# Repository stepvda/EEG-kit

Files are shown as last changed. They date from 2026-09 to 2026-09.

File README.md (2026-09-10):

# EEG Field Kit — Design & Production Package v2.4

**TI One Voice research programme** — [one.witysk.org](https://one.witysk.org), Brussels, Belgium
Board revision B · 2 September 2026

The complete manufacturing package for **EEG-CAR-01 Rev B**: a battery-powered, 16-channel EEG headset
built around an ESP32-S3 carrier board, together with the helmet and enclosure, the electrode harness,
the firmware, the production test programme and fixtures, and all the packing, quality and regulatory
documentation needed to produce the finished kit — flight case included.

The package is designed so that a manufacturer can quote, review and build from it directly: the
Gerbers, drill files, netlist, BOM and CPL files are included, along with every printed part, the
assembly work instructions and an end-to-end test programme that runs from Chrome over USB. For the
study itself — participants, collaborators, grant bodies and funders — see
[one.witysk.org/studies](https://one.witysk.org/studies).

---

## Status at a glance

**Nothing in this package has been manufactured or measured.** No board has been fabricated, no part
has been printed, no firmware has been flashed to silicon, and no electrode has touched a person.
Every performance figure is calculated, and each is labelled as calculated where it appears.

| Area | State |
|---|---|
| Carrier board routing | **Complete.** 145 of 145 nets connected, 0 DRC violations. **Released for review under RFQ-EEG-002A — not yet released for fabrication:** no human layout engineer has reviewed it, and 169 connections close at relaxed width or gap. |
| Firmware | **Built and boots under QEMU** (ESP-IDF v5.2.5, esp32s3). Never run on real hardware — no hardware exists. |
| Mechanical parts | 29 STL + 28 STEP released. Nothing has been printed. Foam case insert **not released for cutting** until the helmet shell is measured. |
| Test programme | Written and self-tested (57/57 interop checks). Never run against a physical unit. |
| Production simulation | 193 checks passed, 0 failed, 6 open items. |
| Safety | **Not done.** The safety review gates Phase 2; nothing goes on a head before it. |

**Read [`KNOWN_ISSUES.txt`](KNOWN_ISSUES.txt) before quoting or building anything.** It is the short
list, in one place, of what is wrong with the data as shipped — 6 open items and 22 unapproved
assumptions in 15 sections. Everything in it is also in the controlled documents; the file exists so
that problems are found here rather than at CAM time.

---

## Orientation — read in this order

1. **`README_package_index.txt` + `KNOWN_ISSUES.txt`** — the orientation pair. The index says what
   every folder is for and gives the rebuild commands (its header is stale at v2.2; this package
   is v2.4).
2. **`docs/RFQ-EEG-001 Rev E`** — the actual request: numbered requirements (E-, S-, F-, T-), the
   pricing template, and §9.4's correction-iteration terms for prototypes that arrive not working.
3. **`docs/DSN-EEG-003 Rev D`** — the governing document. Architecture, the carrier board, and the
   precedence rules that decide which document wins when two disagree.

**Precedence:** DSN-EEG-003 Rev D > RFQ-EEG-001 Rev E > ICD-EEG-006 > SCH-EEG-005 > DSN-EEG-002 >
PARTS-EEG-019 > RUL-EEG-021 > the bidder BOM. Where a number appears in a document *and* in
`tools/design.py`, **design.py governs** — `tools/emit_all.py` regenerates every fabrication file
from it in one pass, so the package cannot drift.

---

## Repository layout

| Path | Contents |
|---|---|
| `docs/` | 21 controlled documents (Rev-controlled, in `.md`, `.docx` and `.pdf`): the RFQ, the manufacturing design package, interface control, schematic set, assembly work instructions, harness wire list, test specification, fixture design, quality plan, risk & safety pack, regulatory file (incl. lithium shipping UN3481/PI967), service & refurbishment, participant card, packing & labelling, change control, approved vendor list, production simulation, part register, firmware build & provisioning, rulings register — plus the three workbooks: bidder BOM, internal costed BOM, manufacturer contacts. |
| `kicad/` | **EEG-CAR-01 Rev B fabrication pack:** routed `.kicad_pcb`, DRC report, BOM, two CPL files, fabrication/assembly/copper drawings, PCB spec sheet, machine-readable net report — and `gerber/`: 11 Gerber X2 layers, two Excellon drills, IPC-D-356A netlist, zipped, with a SHA-256 for every file. |
| `kicad/wh-bus-01/` | The second, tiny PCB: 14 × 10 × 0.8 mm bus board that splits the harness LED_V into eight contact-light tails. The helmet doesn't work without it. |
| `schematic/` | SCH-EEG-005 Rev B, an 8-sheet A3 schematic set (PDF + PNGs), generated from `tools/design.py`. Drawings only — there is no editable `.kicad_sch`. |
| `mech/` | Every printed and cut part: `stl/` (29 printable meshes), `step/` (28 parametric solids for dimensioning and inspection), `drawings/` (25 dimensioned sheets), `renders/` (25 shaded views), 7 foam-layer DXFs for the flight case, the hardware schedule and the mechanical release status. |
| `firmware/` | The ESP-IDF project (main.c, drivers, provisioning opcodes) and `release/`: four flashable ESP32-S3 images (bootloader, partition table, OTA data, app) with a SHA-256 manifest and the exact `esptool` command — no toolchain needed to program a board. `firmware/tools/` is the end-of-line provisioning station: ATECC608B keying, serial & calibration writes, signed-stream verification. |
| `webtest/` | **TOOL-EEG-022**, the connectivity test: one self-contained 52 kB HTML file an assembler double-clicks in Chrome to prove browser–computer–USB–device connectivity (no measurement, no server, nothing to install). The interop harness compiles the real `main.c` against ESP-IDF stubs and drives it with the real host protocol module — 57/57 checks green. |
| `fixtures/` | The four production test fixtures of JIG-EEG-009 as buildable data: PCB outlines and netlists (deliberately no copper), printed-part geometry, and RP2040 controller firmware speaking the FIXPROTO v1 line protocol. Nothing here has been built. |
| `records/` | The machine-readable per-unit test record of TST-EEG-004 §12: a JSON Schema, a stdlib-only validator, and a worked example (all-DEFERRED). No unit has been built, so the schema has never met real output. |
| `graphics/` | Board plots (four copper layers, fabrication drawing, drill map, assembly views, 3D renders) and `labels/`: the packing and marking artwork of PKG-EEG-015 — unit label, kit ID plate, 9 foam bay tags, carton set, lithium mark, tamper seal, disinfection card (22 SVG + 11 PDF). |
| `tools/` | The generator: 42 Python modules, 19,072 lines, 27 entry points. `design.py` is the single source of truth for the board; `mech_gen.py` for the printed parts. Five re-runnable verification gates check connectivity, DRC, placement, cross-document consistency and the 15-station production dry run. Every figure in this package can be regenerated from source. |
| `project/` | Why the kit exists: the 3-page partner proposal, the 161-page experiment design v4.2, and the 11-page project plan with its schedule and workstreams (supplier costs are placeholders). |
| `reports/` | Working DRC reports, metrics and the placement checklist from the routing campaign. |
| `constraints/` | Net rules used by the router. |

---

## The board

**EEG-CAR-01 Rev B** — 150.0 × 130.0 mm, four layers (L1 signal, L2/L3 reference planes split
AGND_REF/DGND, L4 signal), 30 connectors, 211 reference designators, 156 nets.

- 3,745 track segments, 552 through vias, 0 duplicates
- 145 of 145 nets one connected copper island; **0 DRC violations**
- Smallest clearance 0.260 mm, narrowest conductor 0.200 mm, smallest plated hole 0.300 mm
- No digital net in the analogue zone; exactly one AGND_REF-to-DGND bridge and one
  HARN_SHIELD-to-DGND bridge

The layout was produced by the programme's own constraint-aware autorouter and verified by
measurement on the finished polygons — but it has **not** been reviewed by a human layout
engineer. The DRC report lists every one of the 169 relaxed connections so a reviewer can go
straight to the places that need attention.

## Firmware

ESP-IDF v5.2.5, target esp32s3, Phase 1 configuration (secure boot off). Four release images with
SHA-256 checksums, a 920-line `main.c` with 16 host commands and 13 provisioning opcodes, drivers
for the ES8388 codec, SDMMC, ATECC608B, MAX17048 gauge and the envelope onset detector.

| What has happened | What it proves | What it does not |
|---|---|---|
| It builds, clean at `-Wall -Werror=all` | The image links and fits | That any of it is right |
| It boots under QEMU (esp32s3) | Bootloader, partition table and `app_main()` behave as written | Any peripheral — QEMU has no PSRAM, SD, ES8388 or ADS1299 |
| It agrees with the browser tool (57/57) | Framing, CRC, opcodes, the S-01 interlock | Anything about ESP-IDF or hardware |

**It has never run on silicon, and no hardware exists.** The SPI timing, every ADS1299 register
value, USB enumeration and the whole analogue front end are assumptions no silicon has answered.
F-08 (block signing) is unimplemented; the ATECC608B config template is only 4 of 128 bytes
reviewed — that write is irreversible, so it gates on a real part.

## Testing & quality

- **TST-EEG-004 Rev C** — the per-unit test: 32 steps T00–T30, with a 5,033-line JSON Schema and a
  stdlib-only validator so any two vendors emit the same record file.
- **JIG-EEG-009 Rev C + `fixtures/`** — four test fixtures as buildable data, with RP2040
  controller firmware passing 154 host checks.
- **TOOL-EEG-022** — the browser connectivity test (`webtest/EEG-Connectivity-Test.html`) and the
  interop harness that keeps firmware and protocol from drifting apart.
- **SIM-EEG-018** — a production simulation that walks one unit through all fifteen stations,
  purchase order to refurbishment: **193 passed, 0 failed, 6 open**.
- **ECO-EEG-016** — the change register that owns the document namespace and explains why
  everything is the way it is.

## Rebuilding the package from source

```sh
python3 tools/run_build.py          # route, pour, check            (~20 min)
python3 tools/emit_all.py --cached  # Gerbers, drawings, schematic
python3 tools/emit_extras.py        # spec sheet, netreport, STEP, manifest
python3 tools/mech_gen.py           # STL and STEP for every printed part
python3 tools/mech_drawings.py      # dimensioned drawings and renders
python3 tools/emit_workbooks.py     # the three spreadsheets
python3 tools/simulate_production.py --report docs/SIM-EEG-018_....md
python3 tools/make_docs.py          # A4 .docx and .pdf of every document

python3 tools/check_consistency.py  # cross-document consistency gate
python3 webtest/build.py            # rebuild the single-file connectivity tester
node webtest/tests/*.mjs            # protocol tests
sh webtest/tests/interop/run.sh     # firmware-vs-protocol interop (57 checks)
```

## Production phases

1. **Phase 1** — 2 prototypes
2. **Phase 2** — 10 kits
3. **Phase 3** — 10 to 40 further kits (25 to 50 total)

## Sponsorship

This study is run by a non-profit and funded by donations and grants that have not yet all been
secured. Any part of the work treated as sponsorship — a discounted prototype build, parts at
cost, donated units — is welcome, in return for named credit in the published open-hardware design
files, acknowledgement in the resulting papers and on the platform, and the case study of an
instrument you built being used in a pre-registered study.

## Licence & contact

Hardware and documents: **CC BY-SA 4.0** · Firmware: **MIT**

**Third-party datasheets are excluded from both grants.** Manufacturer datasheets and other
third-party documents referenced by this package remain the property of their respective
manufacturers, are referenced or redistributed for reference only, and are **not** covered by
the CC BY-SA 4.0 licence above. See [`docs/datasheets/README_datasheets.md`](docs/datasheets/README_datasheets.md)
for the index and [`docs/datasheets/third_party/LICENCE_NOTE.md`](docs/datasheets/third_party/LICENCE_NOTE.md)
for the terms.

**Stephane van der Aa** — Founder, TI One Voice
[one.witysk.org](https://one.witysk.org) · stephane@stepvda.com · +32 493 70 16 01

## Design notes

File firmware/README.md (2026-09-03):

# FW-EEG-001 — EEG field kit firmware

**Revision:** B **Date:** 1 September 2026, corrected 2 September 2026
**Licence:** MIT (the hardware is CC BY-SA 4.0)
**Specification:** `docs/FW-EEG-001_RevC_firmware_build_and_provisioning.md`
**Target:** ESP32-S3-DevKitC-1-N16R8 on EEG-CAR-01 Rev B

## Status, stated plainly

**Corrected 2 September 2026.** This section used to read: "This firmware **has never been
compiled against a real ESP-IDF installation and has never run on hardware.** It is the
specification in executable form. Five drivers are stubs: the ES8388 codec, the SDMMC
layer, the ATECC608B, the MAX17048 gauge and the envelope onset detector."

Both halves of that are now out of date, and the replacement is deliberately narrow,
because three different things have happened to this source and they prove three different
amounts.

| What has happened | Date | What it proves | What it does not |
|---|---|---|---|
| **It builds.** ESP-IDF **v5.2.5**, target `esp32s3`, `sdkconfig.defaults` + `sdkconfig.phase1`, clean at ESP-IDF's default `-Wall -Werror=all`. Images and a SHA-256 manifest in `release/` | 2 Sep 2026 | every ESP-IDF header, Kconfig option and TinyUSB macro this source names resolves; both `_Static_assert`s held; the image links and fits | that any of it is *right*. A register value that assembles is not one the ADS1299 accepts |
| **It runs under QEMU.** `qemu-system-xtensa -M esp32s3`, one full boot, captured in `release/qemu_boot.log` | 2 Sep 2026 | the image boots, the bootloader reads **this** partition table, the app loads from `factory` at `0x20000`, `app_main()` runs, and the microSD, codec and ring-buffer paths behave as written | every peripheral. QEMU's `esp32s3` has **no** octal PSRAM, **no** microSD, **no** ES8388 and **no** ADS1299 |
| **It agrees with the browser tool.** `sh webtest/tests/interop/run.sh` compiles this `main.c` on a development host against ESP-IDF stubs and drives it with the real protocol module: **57 checks, all passing** | 2 Sep 2026 | framing, CRC, header, opcodes, the acknowledgement layout, the S-01 interlock and the `0x4A`/`0x4B` split | nothing about ESP-IDF, the descriptors or any peripheral |

**It has never run on hardware, and no hardware exists.** No board has been fabricated and
no unit has been assembled. The daisy-chain order, the SPI timing, every ADS1299 register
value, the USB enumeration and the whole analogue front end are still assumptions that no
silicon has answered. No safety engineer has reviewed this design.

**The drivers are written and none of them has run.** `drivers.c` implements the ES8388
codec, the one-bit SDMMC layer, the ATECC608B, the MAX17048 gauge and the envelope onset
detector — they are not stubs any more — but writing a driver and proving one are different
claims and only the first has happened. Not one I2C address, register write or timeout in
that file has been answered by a part. Under QEMU the microSD and codec bring-up both timed
out and both degraded gracefully, which is a bring-up *behaviour* test and nothing more:
QEMU emulates neither part, so a timeout is the only answer it could have given.

**One thing genuinely is not written.** The block-signing task does not exist — no SHA-256,
no chained digest, no signing call, nothing declares it — so `FT_SIGNATURE` frames are never
emitted and TST-EEG-004 T16 has no input at all. F-08 is unimplemented, not merely untested.

Completing bring-up and getting a clean enumeration on Windows, macOS and Linux is the
first task of the firmware volunteer, and TST-EEG-004 step T5 is its acceptance test. The
open defects are FW-D04, FW-D05, FW-D06, FW-D07, FW-D09 and FW-D10; the specification
carries them with an acceptance test each.

What package v2 adds over v1, which shipped `main.c` alone:

| File | What it is |
|---|---|
| `CMakeLists.txt`, `main/CMakeLists.txt` | the ESP-IDF project |
| `main/idf_component.yml` | pinned dependency versions — the TinyUSB descriptor macros moved between releases, and an unpinned build is a silent difference between units |
| `dependencies.lock` | what the component manager actually resolved: IDF 5.2.5, `esp_tinyusb` 1.4.5 |
| `sdkconfig.defaults` | PSRAM in octal mode, USB device, partitions, secure boot, flash encryption, IRAM placement for the DRDY path. Every line is a requirement |
| `sdkconfig.phase1` | the Phase 1 overlay — turns secure boot, flash encryption and anti-rollback off so the two prototypes burn no eFuses and stay re-flashable |
| `sdkconfig.qemu` | the emulator overlay. **Not a configuration for any unit** — see below |
| `partitions.csv` | A/B OTA with rollback, a calibration NVS partition and a provisioning NVS partition |
| `main/board_pins.h` | **generated from `tools/design.py`** so the firmware and the board cannot disagree |
| `main/drivers.h`, `main/drivers.c` | the peripheral API `main.c` calls, and its implementations |
| `tools/provision.py` | the end-of-line provisioning script of RFQ F-18 |
| `tools/verify_stream.py` | the host verifier used at T5, T13, T14 and T16 |
| `release/` | **added 2 September 2026**: the built images, `manifest.json`, `size.json` and `qemu_boot.log` |

## Build

There are two builds, and which one you run decides whether the unit can ever be
re-flashed. **Phase 1**, the two prototypes, and the build that produced `release/`:

```sh
. $IDF_PATH/export.sh          # ESP-IDF v5.2.5
idf.py set-target esp32s3
idf.py -DSDKCONFIG_DEFAULTS="sdkconfig.defaults;sdkconfig.phase1" build
```

**Phase 2 onward**, production, from `sdkconfig.defaults` alone:

```sh
idf.py build
```

`sdkconfig.defaults` enables secure boot v2 and flash encryption in release mode. Build a
prototype that way by mistake and its bootloader burns the eFuses on first boot, after
which UART re-flashing is refused for the life of the board — so the Phase 1 rule is that
prototypes **burn no eFuses at all** (RUL-EEG-021 section B), and `sdkconfig.phase1` is how
that rule is kept. Never move between phases by editing `sdkconfig.defaults`; the overlay
is the only switch. FW-EEG-001 section 2.4 lists all three files in full and section 7.5
states the eFuse phasing.

The release image is signed by the programme before it reaches the manufacturer. The
manufacturer flashes a pre-signed binary and never holds the signing key (RFQ F-19).
`CONFIG_SECURE_BOOT_BUILD_SIGNED_BINARIES=n` is deliberate: the build container never holds
the key, and signing is a separate offline step.

### What the first real build cost, and why it is written down

Five things had to be corrected before `idf.py build` completed, and none of them was a
protocol defect — every one was a project or configuration defect that reading the source
could not have found. They are recorded here because the same five will bite anyone
building this from a clean checkout of an older revision.

* `esp_driver_i2c` **does not exist at ESP-IDF 5.2** — the I2C driver was split out at 5.3 —
  and `idf_component.yml` permits `>=5.2,<5.4`, so the configure step stopped with
  "component could not be found". `main/CMakeLists.txt` requires `driver`, which provides
  I2C across the whole pinned range.
* `CONFIG_BOOTLOADER_APP_ANTI_ROLLBACK=y` had been appended to `sdkconfig.phase1` **below**
  the deliberate `=n`. A later duplicate of the same key silently wins, so the Phase 1
  intent was being undone by a line that read as an addition. ESP-IDF also refuses
  anti-rollback on a table carrying a `factory` partition, and `partitions.csv` has one, so
  the build stopped there — which is how it was found.
* **`CONFIG_TINYUSB_VENDOR_ENABLED` is not an option that exists** in `esp_tinyusb` 1.4.x,
  and ESP-IDF warns rather than fails on an unrecognised key. So the setting looked present,
  `CFG_TUD_VENDOR` stayed 0, `tusb.h` declared none of the `tud_vendor_*` functions, and the
  WebUSB interface this device is built around would simply not have existed. The real key
  is `CONFIG_TINYUSB_VENDOR_COUNT=1`.
* Three descriptor callbacks — `tud_descriptor_device_cb()`, `tud_descriptor_configuration_cb()`
  and `tud_descriptor_string_cb()` — were defined here **and** in `esp_tinyusb`, and the link
  failed with three "multiple definition" errors. With `CONFIG_TINYUSB_DESC_CUSTOM=y` you
  supply the descriptors as *data* through `tinyusb_config_t` and the component owns the
  callbacks. `tud_descriptor_bos_cb()` stays in `main.c`, because the component defines none
  and without a BOS descriptor there is no WebUSB and no MS OS 2.0 capability.
* The five `sdkconfig` lines the specification had listed as "must be added before the first
  build" were still absent. They are in both configuration files now.

### What it measures

| Figure | Value | Reading |
|---|---|---|
| Image, as `idf.py size` reports it | **405,245 bytes** | 13 % of the 3 MB `factory` slot. Ample |
| `release/eeg_field_kit.bin` on disk | 405,360 bytes | the same image plus padding and the appended SHA-256 |
| DIRAM used | 88,799 of 345,856 (25.7 %) | ample |
| **Static IRAM used** | **16,383 of 16,384 — one byte free** | **not a pass.** See below |

The IRAM figure is a cliff, not a margin: the next function anyone marks `IRAM_ATTR` fails
the link with an error naming a section rather than a cause, and this design has more
interrupt work coming. Turning off the SPI-slave and gptimer ISRs — neither of which this
firmware uses, and both removed in `sdkconfig.phase1` — **did not move the figure by a
single byte**, so it is not those. The change is kept because carrying handlers for a bus
and a timer this firmware does not use is wrong either way, but it is **not** the fix.
Either the pool is genuinely full and a bring-up engineer must choose what leaves IRAM, or
`esp_idf_size` is reporting against a fixed 16 kB window that is not the real limit on an
ESP32-S3 with octal SPIRAM and XIP. Reading the linker map against hardware settles it;
guessing at `sdkconfig` from here does not. Carried as FW-EEG-001 section 10 item 17 and
SIM-EEG-018 open item 1.

The build was made on a developer machine from a working tree with uncommitted changes —
the boot log records the app version as `e91f9d58-dirty` — so the SHA-256 list in
`release/manifest.json` is **not yet reproducible**. Rebuilding from a clean tree in the
pinned `espressif/idf:v5.2.5` container is open.

## Running it without hardware

```sh
idf.py -DSDKCONFIG_DEFAULTS="sdkconfig.defaults;sdkconfig.phase1;sdkconfig.qemu" build
```

then a merged flash image under `qemu-system-xtensa 9.0.0 (esp-develop)` with
`-M esp32s3 -m 4M`, which is what the capture records.
`release/qemu_boot.log` is that capture. **It is an emulator, not a unit.** What the boot
settles is the part that needs no peripheral: the image boots, the bootloader reads this
partition table row for row, the app loads from `factory`, `app_main()` runs, the microSD
and ES8388 bring-up paths degrade gracefully instead of aborting, and the ring-buffer guard
fires with its named diagnostic. What it settles about register values, the daisy order, SPI
timing, USB enumeration or the contact lights is **nothing**, because none of those parts
exists in the machine.

`sdkconfig.qemu` differs from the shipped build in exactly one option,
`CONFIG_SPIRAM_IGNORE_NOTFOUND=y`, and **must never be used to build a unit**: it turns a
missing 6 MiB ring buffer — which is F-06 and the whole of the retransmit story — from a
refusal to boot into a silent degradation.

The boot ends in `abort()`, and that is correct here: QEMU has no PSRAM, so the ring cannot
be allocated and `app_main()` refuses to carry on without it. It is also the wrong failure
mode for a field device — a unit that aborts in a participant's home cannot be told apart
from a dead battery or a bad cable, because it never enumerates and the browser tool cannot
ask it what is wrong. That is an open item, not a fixed one.

## The pin map is generated, not written

`main/board_pins.h` is regenerated from `tools/design.py`. Do not edit it by hand.

**ECO-EEG-009.** The Rev A map used GPIO35, 36 and 37 for the contact-light shift register.
Those three pins carry the **octal PSRAM** on the -N16R8 variant and are not connected on
this carrier; GPIO45 is the VDD_SPI strapping pin and is also left open. The shift register
moved to GPIO41, 42 and 0, and the microSD interface dropped to one-bit SDMMC to free them.
70 kB/s is needed at 1000 Hz and about 2 MB/s is available, so the headroom is ample.

## Contact lights

**Written 2 September 2026.** This section used to describe the phase scheme as a
specification; it is now what the source does. `lights_phase()` and `lights_task()` in
`main.c` drive it, FW-D16 is closed, and **RFQ E-27 is met in the source**. It has never
been run: no unit exists, and QEMU has no shift register.

Eight two-lead bicolour LEDs, one per site, sit between their `LEDn` line and the `LED_V`
common. Phase A drives `LED_V` high and the wanted sites low, which shows green; phase B
drives `LED_V` low and the wanted sites high, which shows red; a site lit in both phases
shows amber.

The colour comes from the converter's own lead-off measurement, which is what E-27 asks for,
read at **two comparator thresholds**: a site that trips neither is **green**, one that trips
only the sensitive threshold is **amber** — marginal, re-gel it — and one that trips both is
**red**. The insensitive set is a subset of the sensitive one, so the three states are
exhaustive and cannot overlap.

*Corrected 2026-09-02 (FW-D17).* This read that the colour came from **both** halves of the
lead-off word, `LOFF_STATP` and `LOFF_STATN`. It could not: **the montage is single-ended**,
J2 carries IN1 to IN8 with one shared `SRB1` reference, and `ads_init()` enabled
`LOFF_SENSP` only — so `LOFF_STATN` read zero for every channel for ever, `bad = p & n` was
always zero and **red was unreachable**. Enabling `LOFF_SENSN` would not have fixed it
either: with `SRB1` closed, all eight N bits report the one shared reference and carry no
per-site information at all. Sweeping `COMP_TH` is what this hardware supports.

The alternation is **about 250 Hz, not the nominal 240**. `LIGHT_PHASE_HZ` is 240, so a
half-phase is 2.083 ms; the task delays in FreeRTOS ticks at `CONFIG_FREERTOS_HZ` 1000, so
it quantises to 2 ms. The requirement is "above 100 Hz" and 250 Hz meets it with room; both
half-phases quantise identically, so the duty stays 50/50 and the colour does not shift.
Exactly 240 Hz would need a hardware timer rather than a task delay.

`LED_V` is GPIO48, which is an **input at reset**, so no current can flow through any light
whatever the shift register contains. That is the dark-at-boot guarantee, and it is why
E-27 can be met without a hardware output-enable line. While a block is recording, or when
the host switches the lights off, the task clears the register and returns `LED_V` to an
input — dark by construction, rather than dark for as long as a level stays right.

Forcing a colour is **not** implemented: `CMD_LIGHTS` modes 2, 3 and 4 are accepted and
answered `0x00` OK while the automatic colour continues, where the honest reply would be
`0x0B` not-implemented. Open.

## Provisioning

```sh
python3 tools/provision.py --port /dev/ttyACM0 --serial TIOV-B-0007 \
        --calibration cal_TIOV-B-0007.json --out records/TIOV-B-0007.json \
        --write-config --lock
```

**Corrected 2 September 2026.** This block used to omit `--write-config` and `--lock` and
to describe the run as "ten steps". Neither irreversible action is implied any more: without
`--lock` nothing in a run is irreversible and the run cannot produce a finished unit, which
is what a training or station-validation run wants. `--serial` is checked against the
PKG-EEG-015 format before anything is sent, and the lock additionally needs the serial typed
back or passed with `--confirm-serial`.

The steps are 1, 2, 2b, 2c, 3, 4, 5, 6, 6b, 7, 7b, 8/9 and 10 — each one printed, each one
recorded. **The configuration-zone write and lock run at 2b and 2c, before GenKey**, and not
at step 8: a factory-fresh ATECC608B will not generate a key into a slot whose configuration
has not been written and locked, and locking Microchip's defaults instead is irreversible,
scraps the breakout and produces no device identity. If `--lock` was given and the template
did not reach the part, the run stops **before** the lock rather than continuing. Step 7b
reads the calibration constants back with opcode `0x4A` and compares them byte for byte,
which is TST-EEG-004 T6's acceptance limit and was not executable at all until that opcode
existed. FW-EEG-001 section 7.3 has the full table.

The private device key is generated inside the ATECC608B and cannot be read out by anyone,
including us. The public key fingerprint goes on the enclosure label (RFQ M-03) and the
record travels with the unit.

**None of it has ever been run against a real ATECC608B.** The interop harness drives the
provisioning opcodes and the mode gate against a simulated part, which proves the framing
and the refusals and nothing about the silicon.

Two comments inside `tools/provision.py` and `tools/README_provisioning.md` are known to be
out of date and are not this file's to fix: they describe the old NVS layout — namespace
`"tiov"` in the default partition — which `drivers.c` no longer uses, and their two
skipped-step hints name each other's opcode (`0x4A` and `0x4B` are transposed).

## Verification

```sh
python3 tools/verify_stream.py --file session.bin --pubkey records/TIOV-B-0007.json
```

Decodes the COBS frame stream, checks every CRC-32, checks sequence and sample-index
continuity, counts GAP frames and verifies the ECDSA P-256 block-signature chain against
the exported public key. Exit status 0 only if everything passes, so it can be used as a
test step directly.

Two limits to know before relying on it: it reports `pass` when there are **no** SIGNATURE
frames at all, so T16's operator must assert `signature_blocks > 0` separately; and it has
no `--session-id`, so it roots the chain at 32 zero bytes where TST-EEG-004 T16 roots it at
the session identifier. Both are open items in FW-EEG-001 section 10.

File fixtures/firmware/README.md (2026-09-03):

# Fixture controller firmware -- M1, M2 and M3

**Document:** part of JIG-EEG-009 Rev B, section 8
**Issued by:** TI One Voice research programme (one.witysk.org), Brussels, Belgium
**Licence:** CC BY-SA 4.0
**Written by hand.** This directory is source, not generated output. The only generated
thing near it is `fixtures/MANIFEST.json`, which records the SHA-256 of every file here so
that a fixture's firmware can be tied to a build.

## What this is

Three fixture controllers are named in JIG-EEG-009 and none of them had any source, any
command set or any host contract: M1 in section 1.8 ("Fixture controller, USB CDC, no
radio, Raspberry Pi Pico"), M2 in section 2.4 and M3 in section 4.1 ("a 24-channel relay
scanner card, controller M3"). This is that firmware, and section 8 of the document is the
protocol it speaks.

One source tree, three images, selected at build time:

| Image | Role | Fixture | Drives |
|---|---|---|---|
| `fix_m1.uf2` | M1 | FIX-01 | 83 relays through eleven TPIC6B595, the CD74HC4067 readback, the TCS34725 of FIX-01/E |
| `fix_m2.uf2` | M2 | FIX-02 | the PCM5102A/TPA6132 chain, the two coupler drivers, the two reference electrets, the FIX-02/D marker comparator |
| `fix_m3.uf2` | M3 | FIX-04 | 24 scanner relays through three TPIC6B595, the lid interlock, the 500 V DC gate |

The role is a compile-time choice and not a strap or a stored setting. A fixture that can
be talked into being another fixture is a fixture that will one day drive FIX-04's 500 V
relay map with FIX-01's channel numbers.

## Layout

```
include/fixhal.h     the whole hardware surface -- 17 functions, nothing else
include/fixproto.h   FIXPROTO v1: status codes, the command-table type, the engine
src/fixproto.c       line assembly, tokenising, dispatch, the shared verbs, the watchdog
src/fix_m1.c         M1: relay map, break-before-make, the readback sweep, FIX-01/E
src/fix_m2.c         M2: coupler select, tone, BURST and the marker timestamp
src/fix_m3.c         M3: scanner, the HV gate and the lid interlock
src/hal_rp2040.c     fixhal.h on a Pico.  Compiles.  Has never run.
src/main.c           the loop, and nothing else
test/hal_sim.c       a MODEL OF THE FIXTURE -- relays, readback divider, sensor, marker
test/host_test.c     drives the real firmware against that model
test/stubs/          five stub Pico SDK headers, declarations only
test/run.sh          builds and runs everything below
CMakeLists.txt       the Pico SDK build, for a machine that has the SDK
```

## Build and test

```
sh test/run.sh                     # 154 checks across the three roles, then a HAL compile
cmake -B build -DPICO_SDK_PATH=... # the real images, on a machine with the SDK
cmake --build build
```

`test/run.sh` does two different things and it is worth knowing which is which.

1. It compiles each role against `test/hal_sim.c` and drives it with `test/host_test.c`.
   That is **the real firmware answering real command lines**, and it is what proves the
   two behaviours a reviewer cannot see by reading: that a channel mode change breaks
   before it makes (counted in latch events, not asserted in a comment), and that a
   switching command is refused while HV is armed.
2. It compiles `src/hal_rp2040.c` against the stub headers and checks that all seventeen
   `fixhal.h` functions are defined in the object. That proves the C is valid and the
   contract is met. It proves nothing at all about the peripherals.

## What has not been done

* **No board exists.** JIG-EEG-009 section 7 says no fixture has been built or measured,
  and that includes these. Every pin number in `hal_rp2040.c` is this file's own choice
  against a fixture PCB that has not been laid out.
* **The I2S block is not written.** `hal_tone_start()` on the RP2040 returns 0, `fix_m2.c`
  turns that into `ERR ... 11 UNSUPPORTED`, and the specification the block has to meet is
  in the comment where the code will go. A PIO program written against no hardware and
  never run is a guess with a comment on it, and TST-EEG-004 T12a, T12b and T13 are blocked
  on the host test tool as well (JIG-EEG-009 section 7), so writing one now would buy
  nothing and would look like progress.
* **`RELAY_SETTLE_MS` and `HV_DISCHARGE_MS` are stated constants, not measurements.** Each
  is 10 ms and 5000 ms in the source, each has a comment saying what has to be checked
  against which datasheet, and neither datasheet is in this package.
* **The TCS34725 register numbers are from its datasheet and are checked at run time.**
  `COL INIT` reads the ID register and refuses to go on unless it reads 0x44, so a wrong
  address or a different sensor is a clean error rather than a column of plausible numbers.

## The one thing to read before changing anything

Every response is one line, and every request gets exactly one. Lines beginning `#` are
informational and are never a response. That rule is what lets a host match replies by
arrival order without a sequence number, and the watchdog notice -- the only unsolicited
line the firmware ever emits -- obeys it too.

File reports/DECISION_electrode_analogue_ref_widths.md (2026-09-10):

# Decision paper — the two `confirm` rows in `tools/rules.py`

**Status: evidence and options. NO VALUE IS CHOSEN HERE, and no governing document has been
changed.** Under-width critical nets was one of the seven deficiencies that withdrew Rev B;
this is not a number to invent.

**Why it is urgent.** LAY-EEG-034 is about to be uploaded into JLCPCB's *Layout Requirements*
field, where it becomes part of an order specification. A row marked "confirm" is a proposal,
and a proposal is what a vendor points at when refusing to treat a departure as their error.

---

## 1. First, a correction to the brief

The brief describes the open rows as "`confirm=True` on the ELECTRODE widths and on **the
whole ANALOGUE_REF row**". The source does not say that.

`tools/rules.py` uses `confirm` as a **tuple of columns**, not a flag, precisely so a row can
be part transcription and part proposal:

| Class | `confirm` | Meaning |
|---|---|---|
| `ELECTRODE` | `("width",)` | clearance, layers and vias are requirements; **only the widths are ours** |
| `ANALOGUE_REF` | `("width",)` | **also widths only** — not the whole row |

`ANALOGUE_REF` carries no `cites` string, so nothing else in that row is transcribed from a
governing document either — but the only column *flagged* as a proposal is the width pair.
**`rules.py` governs; the brief is wrong on this point.** What is open is two width pairs and
nothing else.

## 2. What the governing documents fix — the search, and its result

Searched: DSN-EEG-003 Rev D, RFQ-EEG-001 Rev E, RISK-EEG-011 Rev B, ICD-EEG-006 Rev C.

**No governing document fixes a conductor width for either class.** What they do fix:

| Source | What it fixes | Class |
|---|---|---|
| DSN-EEG-003 §3.3 rule 3 | electrode nets routed **on L1**, reference plane continuous beneath, **0.35 mm** clearance rather than 0.20 mm | ELECTRODE — layer, clearance, and by implication no vias |
| DSN-EEG-003 §3.2 | board **minimum track 0.20 mm**; "most conductors are 0.25 mm or wider" | whole board, not a class |
| DSN-EEG-003 §3.3 rule 2 | AGND_REF poured on **L2 and L3** across the analogue zone; joins DGND at R90 only | ANALOGUE_REF — topology, not width |
| ICD-EEG-006 §2.1 | analogue load **about 10 mA per rail** *(calculated: three OPA4376 at 3.04 mA plus the dividers)* | ANALOGUE_REF — current |

DSN-EEG-003 §3.2's "0.25 mm or wider" is a **description of the board**, not a class rule. It
is the sentence a reader is most likely to mistake for a requirement, and it is not one.

## 3. What the electrical requirement implies

### 3.1 Current is not the constraint on either class

IPC-2221, 35 µm outer copper, 10 °C rise — the figures LAY-EEG-034 §61 already uses:
**0.40 mm ≈ 1.29 A**, **0.25 mm ≈ 0.89 A**.

| Class | Actual current | Against 0.25 mm ≈ 0.89 A |
|---|---|---|
| ANALOGUE_REF | ~10 mA per rail (ICD-EEG-006 §2.1) | **89× margin** |
| ELECTRODE | 36.8 µA worst-case single fault (RFQ-EEG-001 E-024); ~300 pA bias in normal use | **24 000× margin** |

Current does not select a width here at any candidate value. Any argument for a wider track
on these two classes is about impedance, noise or robustness — never about heating.

### 3.2 IR drop, computed here

*Derived in this paper, not taken from a document.* 35 µm copper, ρ = 1.72 × 10⁻⁸ Ω·m →
sheet resistance **0.491 mΩ/square**. A 100 mm run is used as a representative worst case
across a 150 × 130 mm board.

| Width | Squares in 100 mm | Track R | Drop at 10 mA (ANALOGUE_REF) | Drop at 36.8 µA (ELECTRODE) |
|---|---:|---:|---:|---:|
| 0.20 mm | 500 | 246 mΩ | 2.46 mV | 9.0 µV |
| 0.25 mm | 400 | 196 mΩ | 1.96 mV | 7.2 µV |
| 0.30 mm | 333 | 164 mΩ | 1.64 mV | 6.0 µV |
| 0.40 mm | 250 | 123 mΩ | 1.23 mV | 4.5 µV |

**ELECTRODE:** the whole 0.20 → 0.40 mm range moves the drop by 4.5 µV, and the conductor is
in series with a **68 kΩ** protection resistor (R1–R16). 196 mΩ against 68 kΩ is **2.9 ppm**.
Track width is electrically irrelevant on this class. Whatever justifies a width here, it is
not the electrical requirement.

**ANALOGUE_REF:** the range moves the drop by ~1.2 mV. Against a ±2.5 V rail that is 0.05 %,
and it is a DC offset largely common to the channels. Not nothing, but not a limit either —
which is what `rules.py` already says: *"the width is for source impedance and for the
mid-rail's noise, not for current."*

### 3.3 The isolation strip and the analogue zoning impose nothing on width

- The isolation keep-out (DSN-EEG-003 §3.3 rule 4) is a **region** — x ≥ 141.0 mm,
  y = 2.0–22.0 mm — free of copper on all four layers. It constrains *where* copper may be,
  not how wide it is, and no ELECTRODE or ANALOGUE_REF net goes near it.
- The zoning rule (rule 1, split at x = 62 mm) is likewise a region rule.
- The **0.35 mm electrode clearance** is the real spatial constraint, and it interacts with
  width: at a fixed pitch, every 0.05 mm added to a track is 0.05 mm taken from the gap.
  `design.py` already records this as the binding constraint in the electrode ladder — "the
  rails, their vias and the sixteen row signals (each owed 0.35 mm)".

## 4. What promoting each row would actually cost — measured, not estimated

Computed from `kicad/EEG-CAR-01_RevB_routed.kicad_pcb`, 3745 segments, each segment's width
against the class minimum now in force. **The total reproduces the 322 under-width findings in
`kicad/EEG-CAR-01_RevB_regraded_ECO-EEG-032.txt` exactly**, which validates the method.

| Class | Min | Segments | Under width |
|---|---:|---:|---:|
| **ELECTRODE** | 0.25 | 492 | **0** |
| **ANALOGUE_REF** | 0.30 | 686 | **186** |
| ANALOGUE | 0.25 | 888 | 77 |
| POWER | 0.40 | 863 | 59 |
| USB, LED_DRIVE, DIGITAL, DEFAULT | — | 816 | 0 |
| **TOTAL** | | **3745** | **322** |

### 4.1 ELECTRODE costs nothing. It is already met at the *preferred* width

492 electrode segments, **narrowest 0.300 mm**. The class minimum is 0.25 mm and the
preferred is 0.30 mm, so the released Rev B geometry already satisfies **the preferred
figure, everywhere, with zero exceptions.**

Promoting ELECTRODE 0.25 / 0.30 from proposal to requirement therefore constrains no
geometry that has ever been drawn. It costs nothing and forecloses nothing.

### 4.2 ANALOGUE_REF is 58 % of every under-width finding on the board

186 of the 322. And the per-net breakdown inverts the class's own justification:

| Net | Segments | Under 0.30 mm | Narrowest |
|---|---:|---:|---:|
| AVSS | 351 | 70 | **0.200 mm** |
| AVDD | 255 | **116** | 0.280 mm |
| **AGND_REF** | 58 | **0** | 0.300 mm |
| AVSS2 | 13 | 0 | 0.400 mm |
| AVDD2 | 9 | 0 | 0.400 mm |

**Every one of the 186 is on AVDD or AVSS — the ±2.5 V rails. None is on AGND_REF.**

That matters, because the justification in `rules.py` for the 0.30 mm minimum is *"for source
impedance and for the mid-rail's noise"*. **The mid-rail already meets it and does not need
it; the rails do not meet it and the justification is not written about them.** The 0.30 mm
figure is binding on exactly the members its stated reason does not describe.

AGND_REF is also mostly **not a track**: rule 2 pours it on L2 and L3 across the whole
analogue zone. Its 58 segments are the stitching between pour and pads, not a distribution
path. A width rule aimed at the mid-rail is aimed at something that is largely a plane.

## 5. The options

### 5.1 ELECTRODE widths

| | Option | What it does | Cost | Against |
|---|---|---|---|---|
| **E1** | Promote **0.25 / 0.30** as-is to a requirement | Makes the rule sheet's electrode row wholly a requirement. Cites this analysis as the basis | **Zero.** Already met at preferred on all 492 segments | The number is still this programme's, now stated as a requirement without a document behind it |
| **E2** | Promote at the **board floor, 0.20 / 0.25** | Introduces no new figure: uses DSN-EEG-003 §3.2's own numbers | Zero | Permits a patient-connected conductor at the same minimum as a digital net. Rev B only reached 0.20 mm on these nets *by relaxing*, and Rev C's brief is not to repeat that |
| **E3** | Promote at **0.30 / 0.35** or wider | Matches what Rev B actually achieved (0.300 mm narrowest) and adds margin | Zero against Rev B geometry, but spends gap in the electrode ladder where 0.35 mm clearance is already binding | Buys nothing electrically (§3.2); may cost routability in the one place the board is tightest |
| **E4** | Leave as a proposal, and mark it as such in LAY-EEG-034 | Honest | Zero | This is the status quo, and it is the thing causing the problem: a vendor will read a "confirm" row as optional |

*What the evidence supports:* the electrical case is silent (§3.2), so this is a robustness
and process judgement, not a calculation. E1 and E3 are both free against the released
geometry. E2 is the only option that introduces no programme-invented number, and is also the
only one that lets a patient-connected conductor sit at the board floor.

### 5.2 ANALOGUE_REF widths

| | Option | What it does | Cost | Against |
|---|---|---|---|---|
| **A1** | Promote **0.30 / 0.40** as-is | Keeps the current figures | **186 relaxations to fix in Rev C** — the single largest geometry cost on the board | Binds hardest on the two nets its own justification does not describe |
| **A2** | Promote at **0.20 / 0.25** (board default) | 10 mA needs 0.20 mm eighty-nine times over (§3.1) | Would clear all 186 | Abandons the source-impedance and noise argument entirely, without having tested it |
| **A3** | **Split the class**: keep AGND_REF at 0.30 / 0.40, put AVDD/AVSS/AVDD2/AVSS2 in their own class at a width chosen for rails | Aligns the rule with the reason. AGND_REF already meets 0.30 at all 58 segments, so that half costs nothing | Clears most or all of the 186 depending on the rail figure chosen | A new class is a change to `rules.py` structure and to the rule sheet; needs its own justification |
| **A4** | Keep as a proposal | Honest | Zero | Same vendor problem as E4 |

*What the evidence supports:* **A3 is the option the measurements point at**, because the
justification and the binding constraint are currently attached to different nets. It is also
the only option that requires a second decision — what width the rails get — rather than
settling the row in one move.

## 6. What is not decided here, and who decides

- **No value is chosen.** Every option above is left open.
- The ELECTRODE row touches a **patient-connected** conductor, so the safety reviewer who
  owns RISK-EEG-011 has an interest even though §3.2 shows the electrical case is empty.
- The ANALOGUE_REF row is an **analogue performance** judgement — source impedance and
  mid-rail noise — which needs whoever owns the front-end design, not a layout engineer.
- **A3 cannot be decided from the documents at all**, because no document has ever stated a
  width requirement for the ±2.5 V rails separately from the mid-rail.

Until a decision is made, `confirm=("width",)` should stay on both rows and LAY-EEG-034
should keep saying so, because that statement is currently true.

---

*Sources: `tools/rules.py`; DSN-EEG-003 Rev D §3.2 and §3.3 rules 1–4; RFQ-EEG-001 Rev E
E-024; ICD-EEG-006 Rev C §2.1; LAY-EEG-034 Rev A; `kicad/EEG-CAR-01_RevB_routed.kicad_pcb`;
`kicad/EEG-CAR-01_RevB_regraded_ECO-EEG-032.txt`. Sheet resistance and IR-drop arithmetic in
§3.2 and the segment tallies in §4 are derived in this paper; the tallies reproduce the
regrade tool's total of 322 exactly. Licence: CC BY-SA 4.0.*

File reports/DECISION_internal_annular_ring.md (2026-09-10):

# Decision paper — IQC-B11's internal annular ring

**Status: evidence and options. QP-EEG-010 has NOT been rewritten and no limit has been
changed.** Vendor answers are still arriving.

**Why it is live.** One fabricator has stated **in writing** that it cannot provide the
report. A second's microsection template does not carry the measurement. When two independent
houses say no to the same line, the requirement is the outlier, not the market.

---

## 1. What IQC-B11 and IQC-B12 each actually rely on

| Row | What it inspects | Evidence it names | Limit | Consequence |
|---|---|---|---|---|
| **IQC-B11** | Inner-layer registration: four layers in the order L1 signal / L2 plane / L3 plane / L4 signal; dielectric thicknesses within ±10 % of §1.1; **internal annular ring measured at a through via** | **Microsection, 1 coupon per fabrication lot**, report retained | four layers in the right order; **ring ≥ 0.025 mm** (IPC-6012 class 2) | Wrong layer order, a missing plane, or any ring below 0.025 mm — **hard reject, whole lot** |
| **IQC-B12** | Layer-to-layer misregistration | **Fabricator registration report *plus* the IQC-B11 coupon** | **≤ 0.125 mm** at every measured location | Above 0.125 mm |
| *IQC-B13* | *Plane continuity and the plane split* | *Artwork comparison every lot; 4-wire DMM on 2 boards; insulation tester at 250 V DC* | *≤ 0.10 Ω corner to corner; AGND_REF–DGND ≥ 100 MΩ* | *hard reject* |

Three things follow, and the third is the useful one.

1. **B11 has exactly one evidence source.** No coupon, no row. There is no alternative
   method written into it.
2. **B12 has two, and only one is the coupon.** A fabricator registration report satisfies
   half of B12 on its own. B12 is therefore *less* exposed than B11 to a house that will not
   microsection.
3. **IQC-B13 does not depend on the coupon at all** — artwork comparison, 4-wire resistance
   and a 250 V insulation test on finished boards. Whatever happens to B11, plane continuity
   and the plane split remain inspectable by methods nobody has objected to. The brief's
   framing that "IQC-B12 leans on the same coupon" is right; it is worth adding that **B13
   does not**, because that limits how much is actually at risk.

Also relevant to any decision: QP-EEG-010 §5 puts "any bare board that failed IQC-B11, B12 or
B13" in **quarantine, no rework**, and prohibits use-as-is concession "for any four-layer
characteristic in IQC-B11 to B13". So these rows are not merely reports — they are wired into
disposition.

## 2. The underlying concern, stated separately from the method

QP-EEG-010 §2.1 says why these rows exist: three characteristics that did not exist on a
two-layer board now have to be inspected — **inner-layer registration**, **plane continuity**,
and the **misregistration limit**.

The concern behind B11 specifically is: **did the inner layers land on the holes?**

This matters here more than on a general-purpose board because of what the inner layers *are*
on this design. DSN-EEG-003 §3.3 rule 2 pours **AGND_REF on L2 and L3 across the whole
analogue zone**, and rule 3 requires every electrode net to run on L1 **with the reference
plane continuous beneath it**. The inner layers are not a convenience — they are the reference
the front end measures against, and the stitching vias are how the two plane regions are tied.
A via that misses its inner land is a stitch that did not happen.

**Why electrical test cannot find it.** A 100 % netlist test to the supplied IPC-D-356A proves
every net is one connected island. A via with a reduced or absent internal annular ring can
still be electrically continuous — the barrel plating touches *some* of the land, or the net
reaches its destination another way. It fails later, thermally or mechanically, and it fails
in the field. That is precisely the defect class electrical test is blind to, and it is why
the requirement was written.

**So the question is not "can we drop B11". It is "what other evidence shows the inner layers
landed on the holes".**

## 3. The arithmetic — verified, and then a problem with it

### 3.1 Verified against DSN-EEG-003 Rev D

Checked against the source rather than taken from the brief:

- DSN-EEG-003 §3.2, vias row: *"0.60 mm pad, 0.30 mm finished hole, **0.15 mm annular ring**,
  tented both sides"* — the document states 0.15 mm directly. (0.60 − 0.30) / 2 = 0.15. ✓
- IPC-6012 class 2 internal annular ring minimum: **0.025 mm**.
- Misregistration budget: 0.15 − 0.025 = **0.125 mm**. ✓

QP-EEG-010 IQC-B12 and ASM-EEG-007 both carry the same 0.15 mm figure, so the package is
internally consistent. **The brief's arithmetic is correct as far as it goes.**

### 3.2 The problem: 0.15 mm is computed from the *finished* hole

Every statement of the 0.15 mm ring in this package derives it from the **0.30 mm finished
hole**. But the internal annular ring is not measured to the finished hole — it is measured to
the **drilled** hole wall, and the drilled hole is larger than the finished one by the plating
allowance, because the copper that makes the hole "finished" is plated *into* the barrel.

The inner-layer land is etched, the drill passes through it, and what is left of that land is
set by the **drill diameter**, not by what the barrel measures afterwards.

Worked, with the plating allowance as the variable:

| Plating per wall | Drill Ø | Internal ring (0.60 − drill)/2 | Budget to 0.025 mm |
|---|---:|---:|---:|
| 0 (the package's implicit assumption) | 0.30 mm | 0.150 mm | **0.125 mm** |
| 25 µm | 0.35 mm | 0.125 mm | **0.100 mm** |
| 50 µm | 0.40 mm | 0.100 mm | **0.075 mm** |

At a routine 25 µm the misregistration budget is **0.100 mm, not 0.125 mm — 20 % tighter than
the number in the plan.** At 50 µm it is 0.075 mm, 40 % tighter.

> **This is asserted, not verified.** It is the standard reading of how IPC-6012 measures
> internal annular ring, and it has **not** been read out of a copy of IPC-6012 by this
> programme. Confirm it before acting on it. If it is right, IQC-B12's stated limit is
> optimistic and the requirement is harder than the plan believes — which strengthens, not
> weakens, the fabricators' objection.

### 3.3 A package gap this exposed

**Nothing in this package states a drill size or a plating allowance.** Searched `design.py`
and DSN-EEG-003: every hole figure is given as a **finished** diameter, and `design.py`
fabrication note 7 reads "Smallest plated hole 0.30 mm (vias)". `wh_bus.py` is the only place
that touches the distinction, and only in passing — *"sizes below are FINISHED hole diameters;
add plating allowance for the tool"*.

So the package hands the fabricator a finished dimension and never states the tool size, and
the annular-ring figure it then quotes back is computed as though the two were the same. That
is a gap independent of what is decided about B11, and it should be closed either way.

### 3.4 Closed at source under ECO-EEG-036 — the gap, not the decision

The gap in §3.3 is now closed where it belongs, in the source, without touching IQC-B11:

- **`tools/design.py`** gains fabrication notes **7a** and **7b**. 7a states that every hole
  size in the package is a **finished** diameter and requires the fabricator to **declare the
  tool size and the plating allowance it used**, per lot, with the note-14 lot documents.
  7b states the external ring (0.15 mm), the internal ring formula, and that the
  misregistration budget falls as the tool grows.
- **DSN-EEG-003 §3.2** gains two rows — *Hole dimensions and the tool*, and *Internal annular
  ring* — and its vias row now says **0.15 mm EXTERNAL** rather than an unqualified "annular
  ring". The plated-hole row now says "finished diameters".

The fabricator is no longer given a finished dimension and asked to meet a ring figure derived
as though no plating existed. **No drill size has been invented here**: the tool is the
fabricator's choice and the requirement is that they declare it.

### 3.5 Verification status of the IPC reading — still asserted, deliberately

WP-C asked whether a copy of IPC-6012 is available. **It is not.** The standard is paywalled
at IPC, and no copy exists anywhere in this repository.

The reading in §3.2 — that the internal annular ring is measured to the **drilled** hole wall
— therefore **stays marked asserted**. It has not been upgraded by finding a secondary source
that agrees, because a secondary source agreeing is not the same as the clause saying so. A
person with a copy should verify it against the edition and clause and record both.

### 3.6 Which documents carry the superseded figure

Classified, because most of these are **not wrong** — they describe the *external* ring, which
really is 0.15 mm. Only the rows that use it as the *internal* ring are defective.

**Defective — uses the external figure as the internal ring:**

| Where | What it says | Status |
|---|---|---|
| `QP-EEG-010` §2.1 **IQC-B12** | "a 0.60 mm pad on a 0.30 mm hole gives a 0.15 mm nominal **internal** annular ring, so class 2's 0.025 mm minimum survives at most **0.125 mm** of misregistration" | **superseded.** NOT rewritten — that decision is open and vendor answers are still arriving |
| `QP-EEG-010` §4.3 **FB-22** | "≤ 0.125 mm, derived in IQC-B12" | consequential on IQC-B12 |
| `QP-EEG-010` §13 **A-23** | audit question resting on the same coupon and budget | consequential |

**Ambiguous — correct as external, but the word "external" is absent:**

| Where | Note |
|---|---|
| `QP-EEG-010` §1.1 geometry table | "0.15 mm nominal annular ring" |
| `docs/RUL-EEG-021` §77 and its twin `tools/RULINGS.md` §79 | vias row |
| `docs/ASM-EEG-007` line 267 | restates the via geometry |
| `docs/ECO-EEG-016` line 1023 | ECO-EEG-012's narrative |
| `tools/router.py` line 37 | a **comment** on `VIA_PAD`, not a computed value — the router does not use the ring figure for anything |

None of the ambiguous set is a defect. They become clearer if "external" is added, and that
is a tidying job, not a correction. **`design.py` and DSN-EEG-003 now say "external"
explicitly**, so the two documents a fabricator is actually sent are unambiguous.

## 4. The alternatives, and what each does and does not prove

The concern is *"the inner layers landed on the holes"*. Measured against that:

| | Option | Proves | Does **not** prove | Vendor friction |
|---|---|---|---|---|
| **1** | **Keep B11 as written** — microsection coupon per lot, ring measured at a through via | Directly and completely: layer order, dielectric thickness, and the ring itself, on a real hole | Nothing relevant is missing. It is the strongest evidence available | **Highest.** Two houses already cannot or do not |
| **2** | **Fabricator registration report** alone | Layer-to-layer registration as *the fabricator measures it*, usually optically on registration targets in the panel border, before or after lamination | **Does not prove the ring at a hole.** Registration targets are in the rails, not at your vias; it is a panel-level statistic, not a measurement of the worst hole. It also does not prove **layer order** | Low — most houses produce one routinely |
| **3** | **The ring added to a standard microsection**, which the house already does | Nearly everything option 1 does, on the house's own coupon and template | Depends on their coupon carrying a **through via of the right drill size**; a standard coupon often sections a plated through-hole of a *different* diameter | **Low to medium.** This is the option the second fabricator's objection actually points at — their template lacks the *measurement*, not the *capability* |
| **4** | **Process-capability declaration** — the house states its registration capability, e.g. ±0.05 mm | That the process is *nominally* capable | Nothing about **this lot**. It is a promise, not evidence, and IQC-B11 exists because promises are not lot evidence | Lowest |
| **5** | **Third-party measurement on the coupon** — the house supplies the coupon, an independent laboratory sections and measures it | The same as option 1, with independence | Adds cost and days per lot; needs the coupon to exist, so it does not help if the house will not carry one in the rails | Medium; moves the burden off the fabricator |
| **6** | **Combination: registration report every lot (B12) + ring-bearing microsection on first article and on any process change** | Layer order and ring at first article; drift caught by the registration report thereafter | A lot-specific defect arising between first article and the next microsection | Medium — a common industrial compromise |

**Two observations that are not recommendations:**

- Option 3 is the smallest change that keeps the evidence. It asks a house to add one
  measurement to a report it already produces, rather than to produce a report it does not.
  The second fabricator's objection was about the *template*, which is a different thing from
  a capability.
- Option 4 is the only one that proves nothing about the delivered lot. If the aim is to
  reduce friction rather than to keep evidence, it is worth being explicit that this is what
  it costs.

## 5. What is not decided here

- **QP-EEG-010 is unchanged.** No limit, method or disposition rule has been touched.
- The **0.025 mm** limit itself is IPC-6012 class 2's, not this programme's, and dropping
  below it would be a departure from the class the whole package is built to — a different
  and larger decision than changing the *evidence*.
- **§3.2 should be settled first.** If the ring is measured to the drilled hole, the real
  budget is 0.100 mm or less and every option above is being judged against the wrong number.
- The **drill-size / plating-allowance gap in §3.3** should be closed regardless of the
  outcome, because the fabricator is currently being given a finished dimension and asked to
  meet a ring figure derived as though no plating existed.
- Vendor answers are still arriving. A third and fourth data point change what "the
  requirement is the outlier" means.

---

*Sources: QP-EEG-010 Rev B §2.1 rows IQC-B11, B12, B13, B15, §4.3 rows FB-21/FB-22, §5
disposition; DSN-EEG-003 Rev D §3.2 and §3.3 rules 2–3; ASM-EEG-007 Rev B; `tools/design.py`
fabrication notes 6, 7, 13, 14; `tools/wh_bus.py`. The 0.15 mm / 0.125 mm arithmetic is
verified against DSN-EEG-003. The drilled-versus-finished-hole point in §3.2 is **asserted
from standard IPC practice and is not verified against a copy of IPC-6012**. Licence:
CC BY-SA 4.0.*

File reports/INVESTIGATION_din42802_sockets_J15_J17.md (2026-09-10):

# Investigation — what are J15, J16 and J17?

**Status: investigation. No part has been chosen and `tools/design.py` is unchanged.**
Changing a non-substitutable patient-connected part is Stephane's decision.

**Read §4 first if you read nothing else.** The evidence points at a footprint change, and it
is far cheaper before the layout desk starts than after.

---

## 1. Provenance — where `SLB1,5-F / LB-I1,5` came from

**It has been in the package since the first commit and has never been corrected.**

| | |
|---|---|
| Introducing commit | **`b18782a`** — the **root commit** of the repository |
| Author / date | Stephane van der Aa, 3 September 2026 |
| Form at introduction | `"Staubli SLB1,5-F / LB-I1,5"` — **byte-identical to today** |
| Commits touching the string since | 8, none of which changed the designation |

**It was never verified against a catalogue, and the package has never claimed it was.** That
second half matters, and it is the most important thing in this section.

`AVL-EEG-017` §1.4.1 — *"The DIN 42802 sockets — the one line with no qualified vendor"* —
already states:

> `design.py` names *Stäubli SLB1,5-F / LB-I1,5*. **That is a class of part, not a confirmed
> PCB part: those are cable and panel parts.** … **No catalogue part has been confirmed to fit
> it.**

The AVL register row reads **OPEN WITH CRITERIA**; the risk table reads **"None qualified …
This is the highest-risk line in the file because it has no vendor at all and it is a
patient-safety part"**, with a **12-week first-article lead time**. `tools/footprint_audit.py`
reports J15–J17 as **OPEN**, never as a pass. `ECO-EEG-012` records the part status as open.

**ECO-EEG-031 is the near miss.** That change audited four part numbers that "could not be
bought or could not be fitted" and corrected three of them outright — the OPA4376 package, the
ferrite bead series, the tactile switch body size. For J15–J17 it did something different: it
added a `NOT_SUBSTITUTABLE` flag so a buyer reading the BOM could see the constraint. Its own
words: *"The part number is a class and not a qualified PCB part, which AVL-EEG-017 §1.4.1 and
ICD-EEG-006 §1 both already said. What was missing is that a buyer reading the BOM could not
see it."*

**So the audit that fixed three neighbouring part numbers deliberately did not fix this one —
it flagged it.** Nobody checked whether the designation exists.

### 1.1 What ECO-EEG-035 added, and what it did not

ECO-EEG-035 fetched and searched both Stäubli catalogues and found **neither designation
anywhere in either**. That is new: the package's prior position was that these were real
Stäubli *cable and panel* parts that merely were not PCB parts. They are not published parts
at all.

**A refinement to AVL-EEG-017 §1.4.1**, which says the named parts "are cable and panel parts".
On the evidence in §3 below, `SLB1,5-F` and `LB-I1,5` are **not Stäubli designations of any
kind**. The AVL's conclusion — no qualified vendor, sample required — is unaffected and
correct. Its characterisation of the two strings is not. **AVL-EEG-017 is not amended here.**

### 1.2 The part of this that is a communication error, not a package error

The package has said "class, not a confirmed part; OPEN; none qualified" consistently and in
several documents. **Three manufacturers were nevertheless told in writing that the part was
genuine and non-substitutable.** "Non-substitutable" is correct and is what `design.py`
records. "Genuine", in the sense of an orderable catalogue part, is a claim **the package
never made**. One manufacturer has priced something at USD 13.73 each against it, and what
they priced cannot now be identified. That is recorded in ECO-EEG-016 under ECO-EEG-036.

## 2. The requirement, stated without reference to any manufacturer

Assembled from `AVL-EEG-017` §1.4.1, `QP-EEG-010` §11.2, `DSN-EEG-003`, `RISK-EEG-011` and
`tools/fplib.py`. **This is what a candidate must meet. No brand appears in it.**

| # | Requirement | Source |
|---|---|---|
| 1 | Touch-proof 1.5 mm connector to **DIN 42802-1** | AVL §1.4.1 |
| 2 | **Finger-safe to IEC 60601-1 for a type BF applied part**; no accessible conductive part with the mating part withdrawn | AVL §1.4.1; RISK-EEG-011 |
| 3 | Instrument-side member of the pair — the carrier is the machine, not the lead | WH-EEG-008 §3.1.2; RISK-EEG-011 **SR-13** (gender itself is open) |
| 4 | Termination: **one Ø1.7 mm PCB pin on the footprint centre, two Ø1.5 mm retention posts at ±3.5 mm** — *or a documented deviation with a drawing* | AVL §1.4.1; `fplib.py` |
| 5 | Body within **9.8 × 7.8 mm**, 14 mm pitch between adjacent positions | `fplib.py` `DIN42802_1p5mm_Socket` |
| 6 | **Three distinct colours**, recorded per site (EMG1 cheek / EMG2 submental / EMG3 laryngeal) | AVL §1.4.1; WH-EEG-008 |
| 7 | Current rating **≥ 1 A stated on the datasheet** | AVL §1.4.1 |
| 8 | Mating force stated, repeatable over **≥ 500 cycles** | AVL §1.4.1 |
| 9 | Evidence: dimensioned drawing, RoHS/REACH, **ISO 10993-5 and -10** if touchable (S-05), CoC per lot | AVL §1.4.1 |
| 10 | **Class A supplier**; physical sample approved **in writing** before the fleet order | QP-EEG-010 §11.1; AVL §1.4.1 |

Requirement 4 is the one that decides everything below, and it already carries its own escape
hatch — *"or a documented deviation with a drawing"*.

## 3. Candidates, with evidence

**Rule applied: a candidate without a fetched document is not a candidate.** Everything in the
unverified list stays out of the comparison.

### 3.1 Verified — documents fetched and read

| Designation | Manufacturer | Document | Retrieved | Mount | Meets req. 4? |
|---|---|---|---|---|---|
| `MEB1,5-R` | Stäubli | Medical catalogue, doc. **11014109** | 2026-09-10 | **panel**, pressed into a pre-drilled panel | **No** — not a PCB part |
| `MLB1,5-R` | Stäubli | doc. **11014109**, assembly instruction MA H511 | 2026-09-10 | **panel**, surface-mounted or flush into a pre-drilled panel | **No** |
| `LS1,5-B` | Stäubli | doc. **11014109** | 2026-09-10 | **in-line, on a lead** | **No** — wrong end of the pair |
| `MS1,5-S` / `S-MS1,5-S` | Stäubli | doc. **11014109** | 2026-09-10 | **in-line, on a lead** | **No** — wrong end |
| `MLK1,5-B` | Stäubli | doc. **11014109** | 2026-09-10 | in-line coupler | **No** |
| `NL844P` | Digitimer | product page | 2026-09-10 | **lead-end plug**, 1.5 mm female DIN 42802 | **No** — wrong end |

**The decisive negative result.** Stäubli's medical catalogue, searched in full as fetched
text, contains **no occurrence of "PCB", "printed circuit", "solder pin", "through-hole" or
"board mount" anywhere in the document.** Every 1.5 mm DIN 42802 part Stäubli publishes is a
panel part or a cable part.

**No verified candidate meets requirement 4. Not one.**

### 3.2 Unverified — named, not evidenced, kept out of the comparison

AVL-EEG-017 §1.4.1 already directs that these be approached. Nothing here is a candidate until
a document is fetched.

| Lead | Why it is named | Status |
|---|---|---|
| Stäubli, **a PCB-terminated variant of the LB-I1,5 family** | AVL §1.4.1's own first suggestion. Would be bespoke; may carry tooling on top of the 12 weeks | **unverified** — no such variant appears in doc. 11014109 |
| **Wuhan Greentek** | an existing programme supplier (electrodes, kit BOM rows 34–36) with a DIN 42802 range | **unverified** — no document fetched |
| **Plastics One / Bio-Medical Instruments** | AVL §1.4.1 | **unverified** |
| **NEUROSPEC** — "DIN 1.5 mm touch-proof sockets, for soldering" | a solderable socket is the closest description seen to req. 4 | **unverified** — the shop URL redirect-looped and no datasheet was obtained |

**NEUROSPEC is the one worth a person's five minutes**, because "for soldering" is the only
phrase encountered anywhere that suggests a board-terminated part. It is in
`docs/datasheets/OPEN_LOOKUPS.md`.

## 4. The footprint consequence — flagged loudly, as asked

**Every part that exists is a panel part or a cable part. The carrier footprint is a PCB part.
On the evidence, `DIN42802_1p5mm_Socket` describes something no manufacturer publishes.**

`tools/fplib.py`'s own docstring already half-says it: *"Touch-proof 1.5 mm DIN 42802 **panel
socket, PCB-mount version**"* — a panel socket adapted to a board, which is a description of
something that was drawn rather than sourced.

AVL-EEG-017 §3 already names the fallback and its cost:

> The fallback, which needs an ECO, is **a panel-mount socket on a flying lead into a 1×3
> header, which moves the part off the carrier footprint entirely.**

### 4.1 What that costs, if it is taken

| | Change |
|---|---|
| **Carrier** | Three `DIN42802_1p5mm_Socket` footprints leave the board. Their three 1.7 mm plated holes and six 1.5 mm NPTH retention posts go with them — **`design.py` fabrication note 7 currently names 1.70 mm as the largest plated hole on the board**, and note 8's non-plated census changes |
| **Replaced by** | One 1×3 header, or three 1×1 positions, in the analogue zone — a much smaller footprint, on nets that are ELECTRODE class (L1 only, 0.35 mm clearance, no vias) |
| **Harness** | Gains three leads from the panel sockets to the header. WH-EEG-008 gains a part, a length, a colour per site and a pull-test row |
| **Enclosure** | POD-P1 gains three panel apertures. `mech_gen.py` and the POD-P1 drawings change |
| **Documents** | DSN-EEG-003 §3.2 hole census, AVL-EEG-017, WH-EEG-008, PARTS-EEG-019, QP-EEG-010 §11.2, ICD-EEG-006 |

### 4.2 Why the timing is the whole point

**The Rev C layout desk has not started.** The three sockets sit in the analogue zone among
the sixteen protection networks, on the tightest clearance rule on the board. Removing three
9.8 × 7.8 mm bodies and their nine holes, or moving them, is a **placement** change. Placement
is the first thing the layout desk does.

Done now, it is an edit to `design.py` and a re-emission of the Rev C inputs — the same
generators that already produce them. Done after placement, it is a re-place and a re-route of
the most constrained region of the board, and the 15-day layout leg is paid twice.

**This is a recommendation, stated as a recommendation:** settle whether J15–J17 are
board-mounted or panel-mounted **before** the layout desk is released to place, even if the
part itself is not chosen by then. The *mounting decision* is what the layout needs; the
*part* can follow.

## 5. What is not decided here

- **No part is chosen**, and `design.py` is untouched.
- **AVL-EEG-017 is not amended**, though §1.4.1's characterisation of the two strings is
  refined by §1.1 above.
- The **gender question is separate and also open** — `RISK-EEG-011` **SR-13**.
- The **USD 13.73 quotation** cannot be matched to a part; ECO-EEG-036 records it.

---

*Sources: `git log` on `tools/design.py` (`b18782a`, root commit); `docs/AVL-EEG-017_RevC`
§1.4.1, §3 and the J15–J17 register row; `docs/ECO-EEG-016_RevC` ECO-EEG-012 and ECO-EEG-031;
`tools/fplib.py`; `tools/footprint_audit.py`; `docs/QP-EEG-010_RevB` §11.1–11.2; Stäubli
medical catalogue doc. 11014109 and T&M catalogue doc. 11014124, both fetched 2026-09-10;
Digitimer NL844P page, fetched 2026-09-10. Licence: CC BY-SA 4.0.*

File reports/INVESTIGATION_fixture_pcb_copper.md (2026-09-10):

# Stage-one investigation — copper for the fixture boards

**Status: investigation only. No routing has been attempted and no file under `fixtures/` has
been changed.** Stage two is not merely un-started — it is blocked, and by something WP1 was
already looking at. That is the finding.

A manufacturer has asked directly whether they build the fixture boards or we consign them.
**Neither is possible today**, and the reason is not that the work was overlooked.

---

## 1. Which of FIX-01 to FIX-04 are PCBs at all?

Answered from JIG-EEG-009 Rev C, not from the shape of the `fixtures/pcb/` directory.

| Fixture | Is it a PCB? | Evidence |
|---|---|---|
| **FIX-01** | **Yes.** 160.0 × 100.0 mm, two layers | §1.9 outline; `fixtures/pcb/FIX-01/` holds outline, zoning, legend, NPTH drill, constraints and a **217-net, 772-pin** netlist |
| **FIX-02** | **Has a circuit; has no board, and no board was ever specified** | §2.4 BOM is U201 (TLV3201), R201–R205 precision resistors, C201, plus a Pico, a PCM5102A and a TPA6132 breakout, two 47 Ω loads and a TRS plug, **in a Hammond 1590B enclosure**. §6.1 prices **no** "Fixture PCB" line for it |
| **FIX-03** | **No. Not an electronic assembly at all** | §3.3 is a printed PA12 nest plus bought items — USB-C pigtail, P75-B1 pogo block, barcode scanner, powered hub — and "no keys, no secrets, and no ability to sign anything". §6.1 prices no PCB line |
| **FIX-04** | **Yes.** Two layers | `fixtures/pcb/FIX-04/` holds the same file set and a **61-net, 208-pin** netlist; §6.1 prices a PCB line at EUR 72 |

**So the fixture index naming FIX-01 to FIX-04 does not imply four boards. It implies four
fixtures, two of which are boards.** `fixtures/pcb/` containing exactly FIX-01 and FIX-04 is
correct and complete for what the document specifies. Nothing is missing there.

**FIX-02 is the one worth a second look, and it is a design question, not a gap.** It has real
electronics — a comparator, five 0.1 % resistors, a threshold network — presently described as
parts in a box. Whether that becomes a small PCB or stays point-to-point in the 1590B has
never been decided, and JIG-EEG-009 does not decide it. It should not be decided by a
generator quietly emitting a board for it.

## 2. Why copper was deliberately omitted

This was a decision, and both the tool and the released data state it plainly.

`tools/fixture_gen.py`:

> **The fixture PCBs are NOT a fabrication release, and this file does not pretend one.**
> […] What is released is everything that does not need a layout engineer — the outline, the
> mounting holes, the zoning and keep-out artwork, the panel legend, the drill programme for
> the non-plated holes, the complete netlist and the constraint set — because those are
> derivable from JIG-EEG-009 and **the netlist is the thing a layout house cannot start
> without.** Copper is not derivable: laying out 83 relays and 144 precision resistors on two
> layers with a driven guard pour is a person's job […] **Inventing a copper layer against a
> footprint nobody has measured would produce a file a fabricator would build and a board
> nobody could assemble.**

`fixtures/pcb/FIX-01/README_fixture_pcb_data.txt` says the same to the reader who only has the
directory: *"a board fabricated from what is here would be a bare piece of FR-4 with four
holes in it […] The copper is a layout engineer's work and is priced in JIG-EEG-009 §6.1 and
scheduled in §6.3."*

**The work is already costed and scheduled**, which is the strongest evidence that it was
planned rather than forgotten:

| | Hours | EUR |
|---|---:|---:|
| FIX-01 schematic capture, land patterns, placement, routing, DRC and outputs | 46 | 2 530 |
| FIX-04 schematic capture, land patterns, placement, routing, outputs, 500 V creepage check | 15 | 825 |
| *(Controller firmware bring-up on the first boards — related, not layout)* | *24* | *1 320* |
| **One-off engineering, first set only** | **85** | **4 675** |

§6.3 puts the layout leg at **15 working days** and says it is "the only long-lead item […]
the layout-then-fabricate leg is now the longest one at 25 days". All figures are stated in
that document as **calculated estimates at EUR 55/hour, not quotations**.

## 3. Can `tools/fixture_gen.py` emit copper?

**No, and it should not be extended to until §4 is resolved.**

- The generator has no copper machinery of any kind — no track, pour, via, paste or plated-
  drill writer. Every Gerber it emits carries a `G04 NOT A FABRICATION SET` line and the NPTH
  writer states "there is no copper layer".
- It has no autorouter, and adding one would be the wrong instrument. FIX-01 needs a **driven
  GUARD pour** and the §1.3 ratio-leg rule; those are the judgements the 20 priced routing
  hours exist to buy.
- It does have `--check`, which computes the area budget against a **stated** land-pattern
  envelope. That is the honest half of the job and it is already done.

Extending it is therefore not a small job and not obviously the right one. The netlists exist
in both human and machine form specifically so a **layout house** can start.

## 4. The blocker, which is a datasheet

**FIX-01's outline is provisional until one number is read off one datasheet.**

From `fixtures/pcb/FIX-01/README_fixture_pcb_data.txt`:

| | |
|---|---|
| Board area | 16 000 mm² (160.0 × 100.0) |
| Occupied | 9 540 mm² — **60 %**, against a 60 % working limit for a two-layer board of this density |
| 83 relays at | **70.0 mm² each — ASSUMED envelope, not a datasheet figure** |
| Largest land pattern the outline can carry | **70.7 mm²** |
| **Margin** | **1.0 %** |

> "A board that closes only if the relay is at or under the size assumed for it is a board
> that does not close if the assumption is 2 mm out on one axis, so this outline is
> provisional until the datasheet is opened."

The part is the **Omron G6K-2F-Y**, and `tools/fixture_gen.py` names it as "a datasheet this
package does not carry". It is section 7 of the new `docs/datasheets/README_datasheets.md`,
and it is **not resolved there either**: `components.omron.com` refuses automated requests
(HTTP 403), so a person has to open the page.

**Routing FIX-01 before that number is known would spend 46 hours and EUR 2 530 against an
outline that may not close.** JIG-EEG-009 §1.9 notes the enclosure — a Hammond 1590D at
188 × 119 mm — has room for a larger board if one is needed, so the fallback exists; but
changing the outline after routing means routing again.

## 5. What stage two should be, and it is not what the brief describes

The brief's stage two is: *"route the fixture boards from their existing netlists through
`tools/fixture_gen.py`, with the same discipline as the carrier — generated from source, DRC
run in KiCad, rule count asserted, nothing hand-edited."*

Three things about that do not survive contact with the source:

1. **`fixture_gen.py` cannot route and should not learn to.** The carrier's own machine
   routing is exactly what an independent layout engineer rejected — vias in pads, stubs,
   off-centre pad entry, under-width conductors — and it is being redone by a human layout
   desk as Rev C. Applying "the same discipline as the carrier" to the fixtures would mean
   repeating the process that produced the withdrawal, on boards that carry 500 V relay maps
   and a driven guard.
2. **The one dimension it turns on is unknown** (§4). This is the hard blocker.
3. **The programme has already decided this is a person's job, priced it and scheduled it.**
   Reversing that is a decision, not a task, and the evidence in §2 argues for keeping it.

**Recommended shape for stage two, for a decision rather than as a plan to execute:**

| | Step | Depends on |
|---|---|---|
| a | Open the G6K-2F-Y datasheet; read the land pattern; check against **70.7 mm²** | a person, WP1 §7 |
| b | If it does not fit: re-size the outline in `fixture_gen.py` (the outline **is** derivable) and re-run `--check` | (a) |
| c | Decide whether FIX-02's circuit becomes a board or stays in the 1590B | JIG-EEG-009 owner |
| d | Commission FIX-01 and FIX-04 layout from a layout house against the released netlists — the 15-day, EUR 3 355 leg already in §6.3 | (a), (b) |
| e | Take the returned copper back in as released data with checksums, as `kicad/gerber/` does | (d) |

Step (a) costs one person ten minutes and unblocks a EUR 3 355 commitment. **Nothing else in
this work package should start before it.**

## 6. What can be answered to the manufacturer today

They asked whether they build the fixture boards or we consign them. The answerable parts:

- **FIX-03 is not a board.** Printed nest plus bought items; nothing to quote as a PCB.
- **FIX-02 has no board and may never have one.** Quote it as an assembled box if they quote
  it at all.
- **FIX-01 and FIX-04 are boards, and the copper does not exist**, so they cannot be built by
  anyone yet — not by them, not by us. What exists is the netlist, the outline, the zoning,
  the legend, the NPTH drill and the constraints, which is what a layout house needs to
  start and is deliberately everything short of a fabrication set.
- If they have a layout capability, **the 15-day leg in §6.3 is a thing they could quote**,
  and that is probably the most useful question to put back to them.

---

*Sources: JIG-EEG-009 Rev C §0, §1.9, §2.1, §2.4, §3.3, §6.1, §6.2, §6.3, §8.8;
`tools/fixture_gen.py`; `fixtures/pcb/FIX-01/README_fixture_pcb_data.txt`;
`fixtures/pcb/FIX-04/`; `docs/datasheets/README_datasheets.md` §7. All euro and hour figures
are JIG-EEG-009's own calculated estimates at EUR 55/hour, not quotations, and nothing in this
package has been built. Licence: CC BY-SA 4.0.*

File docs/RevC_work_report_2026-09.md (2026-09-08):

# EEG-CAR-01 Rev C -- work report

**Not a controlled document.** It is the report on the work of 8 September 2026 that
ECO-EEG-030 to ECO-EEG-033 record, and it says what was run, what the repository
contradicted, what was assumed, and what is still open.
**Licence:** CC BY-SA 4.0

---

## 1. What was run, and what it printed

### 1.1 Baseline, on the untouched tree

| Command | Result |
|---|---|
| `tools/emit_all.py --cached` | **run.** 0 violations, 145 of 145 nets connected, 3 745 segments, 552 vias, minimum clearances 0.260 / 0.285 / 0.285 / 0.275 mm. Every text output reproduced **byte for byte** against the committed files; only the PNG, PDF and zip outputs differed, on embedded timestamps |
| `tools/simulate_production.py` | **run.** 186 passed, 0 failed, 5 open -- **not** the 193 / 0 / 6 the register stated. See 2.1 |
| `kicad-cli --version` | **NOT RUN.** KiCad is not installed on this machine and could not be installed. No ERC and no DRC result is claimed anywhere in this work |

Four Python packages had to be installed before anything would run at all: `shapely`,
`scikit-image`, `numpy` (present) and `trimesh`. **`cadquery` could not be installed**: the
machine had 472 MB of free disk and `cadquery-ocp` needs several times that. `tools/mech_gen.py`
imports cadquery at module scope, so it cannot even be imported here, and **no printed part was
regenerated in this work**.

### 1.2 The Rev B geometry under the new rule set

`tools/grade_revb.py`, on the released `kicad/EEG-CAR-01_RevB_routed.kicad_pcb` and
`tools/routed.pkl`, census checked first (3 745 segments, 552 vias):

| Finding | Rule | Count |
|---|---|---|
| 1 | vias inside an SMD pad | **67** |
| 2a | dangling track ends | **5** |
| 2b | redundant copper loops outside a plane | **221**, on 22 nets |
| 3 | angle below 90 degrees between two segments | **171** |
| 3 | segments off a 0/45/90/135 degree axis | **158** |
| 4 | off-centre pad entries | **299** |
| 5 | conductors under their class minimum | **322** |
| 5 | net classes on a forbidden layer | **50** |
| 5 | vias on a class that forbids them | **18** |
| | **total** | **1 311** |

The Rev B DRC report is **not withdrawn**. It measured the twelve rules it had, correctly.

Two counts in `tools/drc_geometry.py` were wrong before they were right, and both are recorded
in the source rather than quietly fixed. The loop check first modelled copper as touching
polygons and reported **3 356** loops, where three mutually touching polygons are not a loop;
re-modelled topologically -- junctions as nodes, segments as edges, T-junctions split -- it
reported **476**; excluding degenerate edges, where a segment's two ends land on the same via,
it reports **221**. The first two numbers are wrong and are not quoted anywhere else.

### 1.3 The schematic against the design source

`tools/sch_netlist.py` parses the emitted `.kicad_sch` files back -- pin geometry from their own
embedded `lib_symbols`, wires, junctions, labels, hierarchical labels, power symbols -- and
diffs. It does not ask the generator what it meant.

| | `design.py` | schematic |
|---|---|---|
| nets | 156 | **156** |
| pins | 614 | **614** |
| structural problems | -- | **0** |
| netlist differences | -- | **0** |

It found four real errors on its first run: R50, R51, R52 and R94 were wired by geometry rather
than by pin number and had pin 2 where `design.py` has pin 1, and R94/R95 were drawn as a
divider instead of two I2C pull-ups. A resistor is symmetric, so the circuit was right and the
netlist was wrong. Both are fixed and the helper that caused it now wires by pin number.

### 1.4 ERC, DRC and the collision check

| Check | State |
|---|---|
| `kicad-cli sch erc` | **NOT RUN.** KiCad is not installed |
| `kicad-cli pcb drc` | **NOT RUN.** Same |
| structural ERC (`tools/sch_netlist.py`) | **run: 0 findings.** Every pin on a net; no designator placed twice and every unit of a multi-unit part placed once; no accidental single-pin net; every power net driven by a power symbol |
| board read-back (`tools/emit_revc.py`) | **run: passes.** 211 footprints, 636 pads, 156 nets, **0 segments, 0 vias**, 37 locked, netlist identical to `design.py`, every rule area present under the name the `.kicad_dru` uses, project classes and all 156 assignments complete, `track_dangling` at error |
| footprint audit (`tools/footprint_audit.py`) | **run: 183 PASS, 0 FAIL, 3 OPEN, 0 UNRECOGNISED, 25 fabricated features** over all 211 designators |
| collision check (`tools/collision_check.py`) | **run: 15 findings. Three of its four cases are open.** See 1.5 |
| `.kicad_dru` bracket check | **run: 37 rules, balanced** |
| STEP structural check | **run: all files closed, no dangling entity reference.** **No STEP reader was available**, so no CAD kernel has opened them |
| `tools/simulate_production.py`, after | **run: 193 passed, 0 failed, 7 open** |

### 1.5 The collision check, in full

| Case | Result |
|---|---|
| A -- carrier parts against the plate underside | **clear.** Tallest is J15 at 10.00 mm against a plate underside at 18.0 mm |
| B -- the DevKit against the plate opening | **OPEN. The opening is 2 mm too short.** J6/J7 are 1x22, so the pin span is 53.34 mm and the ESP32-S3-DevKitC-1 PCB is 63.0 mm: it needs carrier Y 3.2 to 66.2 mm and MP-01's opening runs 4.0 to 65.0 mm |
| C -- modules against each other and jumper reach | **OPEN. Six of twelve cannot be placed**, and **four cannot reach their connector within the 60 mm of ICD-EEG-006 section 3.2 from any position on the plate** -- M4 to J10 is 86 mm at best, M5 to J11 is 72 mm at best. That 60 mm is a crosstalk limit |
| D -- plan area | **OPEN. 17 356 mm2 of modules into 12 409 mm2 of plate: 140 % fill** |

**Case D does not rest on the assumed envelopes.** The two ADS1299 boards alone are 7 345 mm2,
**59 % of the net usable plate**, and that figure is the Raspberry Pi HAT mechanical standard
rather than a guess: the PiEEG-8 is a Pi shield. **Halving every other envelope still leaves
12 351 mm2 against 12 409 mm2.**

### 1.6 Reproducibility

Two consecutive runs of `tools/emit_all.py` produce **byte-identical SHA-256 checksums across
all 51 files** of the handover set. Every uuid in the schematic is uuid5 over a fixed
namespace, so a regeneration is diffable against the last one.

---

## 2. Where the repository contradicted the brief

| # | The brief said | The repository says |
|---|---|---|
| 1 | the simulator's last run was **193 passed, 0 failed, 6 open** | On this machine the untouched tree printed **186 / 0 / 5**. Six checks need `cadquery` and one open item needs `trimesh`; installing `trimesh` gave 187 / 0 / 6, and `cadquery` could not be installed. **The register's 193 was obtained on a machine with cadquery.** The run behind this work prints **193 / 0 / 7** and is *not the same 193*: six checks were added and six lost, and they cancel. A machine with cadquery would print **199** |
| 2 | "four op-amp packages moving from SOIC to TSSOP" | **Three.** U1, U2 and U3. There is no U4; U7 is the SOT-23-5 comparator |
| 3 | the Murata part number should be corrected "if it does not encode 600 Ω" | The part number **does** encode 600 Ω -- Murata's own numbering page reads the three figures as two significant digits and a count of zeros, so `601` is 600 Ω. The reviewer's reading was wrong. **The defect is elsewhere and is real**: `PG` is the large-current series and it is not made at 600 Ω in 1608, whose range stops at 470 Ω. `BLM18PG601SN1D` is not a part. Corrected to `BLM18AG601SN1D` |
| 4 | three BOM errors | **Four.** `Omron B3F-4055` is a **12 x 12 mm** switch on a 6 x 6 mm land pattern, and at 260 gf it also misses AVL-EEG-017's own 160 ± 50 gf window. Found by the audit the brief asked for, not by any reviewer. Corrected to `B3F-1052` |
| 5 | ICD-EEG-006 section 1 is the one home of the connector table | **Four of its coordinates disagreed with `design.py`**: J4 (41.0, 36.0 against 41.0, 50.0), J9 (66.0, 78.0 against 114.0, 62.0), J22 (30.0, 116.0 at 90° against 15.7, 73.5 at 270°) and J26 (128.0, 104.0 against 117.0, 8.0). Two moved at ECO-EEG-018 and the table never followed. `design.py` governs; the table is corrected and RUL-EEG-021 ruling 6 is added |
| 6 | `design.py` carries 68 kΩ (ECO-EEG-024) | The **value** did. `design.py`'s `NOTES`, which are printed onto the fabrication and assembly drawings, still said **47 kΩ**; also said the analogue rails arrive at "J2 pins 11-14", where J2 has ten ways and they arrive at J23; and said the keep-outs are clear "on both layers" on a four-layer board. All three corrected |
| 7 | emit `kicad/EEG-CAR-01_RevC_unrouted.kicad_pcb` **and** `EEG-CAR-01_RevC.kicad_pro` | **Those two names are incompatible.** A KiCad project expects its board to share the project's stem; a differently named board opens standalone, without the net classes, the 156 assignments or the DRC severities. The board is `EEG-CAR-01_RevC.kicad_pcb`. See open question 1 |
| 8 | the rule sheet is **one page** | It is **three**. See open question 2 |
| 9 | five release-state paragraphs say "released for review" | **Sixteen documents did**, sixty-two occurrences. The five named are corrected, and so are the other six live statements in the four documents this round re-issued. Eight documents it did not re-issue still carry it. See open question 3 |
| 10 | the DRC report is the authority for the routed result | It is, and it is authoritative **about the rule set it had**. RUL-EEG-021 ruling 5 now says that a DRC report states the rule set it measured against |

---

## 3. Assumptions

Every one is registered or flagged. None is a sign-off.

| # | Assumption | Where it is registered | Confidence |
|---|---|---|---|
| 1 | The twelve module envelopes, and their placement on MP-01 | **ASM-EEG-023 Rev B, MECH-D6-MODULE-ENVELOPES**, new and **blocks a build** | judgement. **No vendor drawing was consulted for any of them.** Two are form-factor derived: the PiEEG-8 is a Pi HAT (65.0 x 56.5 mm) and the Pololu S13V15F5 is a 0.5 x 0.8 inch board |
| 2 | `ELECTRODE` minimum width 0.25 mm, above the board's 0.20 mm floor | `tools/rules.py`, flagged `confirm`; printed in LAY-EEG-034 section 5 | judgement. Open question 4 |
| 3 | `ELECTRODE` on L1 only, no vias | same | DSN-EEG-003 section 3.3 rule 3 read literally. Open question 4 |
| 4 | `ANALOGUE_REF` minimum width 0.30 mm | same | impedance, not current. Open question 4 |
| 5 | Pad entry within 25 % of the pad's minor dimension | `tools/rules.py`; LAY-EEG-034 section 6 | judgement: finding 4 has no number in it |
| 6 | The schematic sheet split, nine sheets | `tools/emit_kicad_sch.py`, checked to be a partition of `design.C` | judgement |
| 7 | KiCad 8 -- `(kicad_sch 20231120)`, `(kicad_pcb 20240108)` | the handover README, with an offer to re-emit | assumed, as the brief instructed. Open question 5 |
| 8 | Carrier component heights per footprint class | `tools/mech_bodies.py`, each with its source | datasheet, except the DIN 42802 socket at 10.00 mm, which has no qualified part |
| 9 | The DevKit stands 13.6 mm and its PCB is 63.0 x 25.5 mm | ICD-EEG-006 section 4 (*calculated*) and Espressif's published outline | derived |

---

## 4. Open questions

**1. The board file name.** The brief asked for `EEG-CAR-01_RevC_unrouted.kicad_pcb` beside
`EEG-CAR-01_RevC.kicad_pro`. A KiCad project expects board and schematic to share its stem, and
a board opened standalone loses the eight net classes, the 156 assignments and the severity that
makes `track_dangling` an error -- most of the specification.
*Recommended default, and what is implemented:* the board is `EEG-CAR-01_RevC.kicad_pcb`, and
that it is unrouted is said in its title block, its comments, LAY-EEG-034 and the README.

**2. The rule sheet is three pages, not one.** Compressing it means dropping the derivation of
each net-class number, and a rule whose reason is invisible is a rule that gets relaxed at the
first difficulty.
*Recommended default:* leave it at three. If one page is needed for the order paperwork,
sections 5 and 6 alone fit on one and the rest becomes an annex.

**3. Eight documents still say the data is "released for review".** ASM-EEG-007, PARTS-EEG-019,
QP-EEG-010, REG-EEG-012, RFQ-EEG-001, RISK-EEG-011, SVC-EEG-013 and TST-EEG-004. Three of them
are out of scope by instruction (RISK-EEG-011, REG-EEG-012 and the research documents), and
RFQ-EEG-001 additionally carries E-26's self-contradicting switch class.
*Recommended default:* one sweep ECO covering the five that are not out of scope, plus the RFQ
at its next issue. It is mechanical and it is the defect RUL-EEG-021 section C ruling 4 forbids.

**4. Four net-class numbers need your confirmation** before the order goes out, because they
constrain the contractor and they are this programme's proposals, not transcriptions: the
`ELECTRODE` minimum width of 0.25 mm; `ELECTRODE` restricted to L1 with **no vias at all**; the
`ANALOGUE_REF` minimum width of 0.30 mm; and the 25 % pad-entry tolerance.
*Recommended default:* confirm all four. The electrode restriction is the one worth a second
look -- it is DSN-EEG-003 section 3.3 rule 3 read literally and it is achievable on the present
placement, but if the contractor says it forces a respin, relaxing it is a decision and not a
concession to be made silently.

**5. Which KiCad version is JLCPCB on?** Everything is emitted for KiCad 8. Re-emitting for
another major version costs nothing because it is generated.
*Recommended default:* ask Lyle He before the order and re-emit if the answer is not 8.

**6. MP-01 cannot carry twelve modules.** 140 % fill, and the plate's DevKit opening is 2 mm
short. Four routes would each move it -- a larger plate; a second tier of standoffs; an ADS1299
breakout that is not a Pi HAT, which AVL-EEG-017 section 2 M1 permits under qualification even
though the *device* may not change; or moving the modules whose jumpers cannot reach onto the
carrier as fitted parts. **None is decided and none is costed.**
*Recommended default:* buy one of each module and measure it before deciding anything, because
ten of the twelve envelopes are assumptions. The two that are not -- the ADS1299 boards -- are
59 % of the plate on their own, so **the measurement most likely to settle it is the PiEEG-8's
actual outline.**

**7. Should the in-house router produce a reference route for comparison?** It was not done:
the brief puts it last and everything ahead of it took the time.
*Recommended default:* no, until the contractor's placement is in. A reference route against a
placement nobody has confirmed compares two guesses.

**8. `firmware/main/board_pins.h` is still hand-maintained** against a check in
`tools/simulate_production.py`. Untouched here, as instructed; no pin assignment moved, so it
did not need to move.
*Recommended default:* leave it until a change forces a pin move, then generate it.

---

## 5. The handover set

`kicad/RevC_layout_inputs/` -- **51 files, 2.6 MB**, with `SHA256SUMS.txt` carrying a SHA-256
and a one-line description for each. The manifest is the authority and is not reproduced here.

| Group | Files |
|---|---|
| project | `EEG-CAR-01_RevC.kicad_pro` |
| schematic | `EEG-CAR-01_RevC.kicad_sch` + nine sheets, `EEG-CAR-01.kicad_sym` |
| board | `EEG-CAR-01_RevC.kicad_pcb`, `EEG-CAR-01_RevC.kicad_dru` |
| netlist and BOM | `EEG-CAR-01_RevC-IPC-D-356A.ipc`, `EEG-CAR-01_RevC_BOM.csv`, `footprint_audit_RevC.md` |
| placement | two provisional CPLs, `EEG-CAR-01_RevC_outline_and_fixed_connectors.dxf` |
| 3D | 22 footprint bodies under `step/footprints/`, three assembly bodies under `step/` |
| evidence | `EEG-CAR-01_RevC_schematic_netlist_check.txt`, `EEG-CAR-01_RevC_collision_check.txt` |
| rules | `LAY-EEG-034_RevA_carrier_layout_rule_sheet.pdf` and `.md` |
| covering note | `README_layout_inputs.md`, `SHA256SUMS.txt` |

**Nothing was sent.** No tool in `tools/` transmits anything.

---

## 6. Commits

| Commit | Work package |
|---|---|
| `c652258` | **WP1** revision bookkeeping and the Rev B withdrawal ECO (ECO-EEG-030) |
| `34feea1` | **WP2** BOM and footprint corrections (ECO-EEG-031) |
| `553bec1` | **WP3** the seven findings encoded as rules, and Rev B regraded (ECO-EEG-032) |
| `e15724c` | **WP4** the native KiCad schematic (ECO-EEG-033 part 1) |
| `b142243` | **WP5** unrouted board, project file and DXF (part 2) |
| `9e96ce1` | **WP6** 3D bodies and the collision check (part 3) |
| `0fb4e9d` | **WP7** LAY-EEG-034, the layout rule sheet (part 4) |
| `4b87f44` | **WP8** the handover set and its README (part 5) |
| `385429a` | **WP9** document register close-out |
| `17c02ad` | **WP9 (cont)** release-state statements in the four re-issued documents |

Documents advanced a letter: DSN-EEG-003 to **D**; ECO-EEG-016, ICD-EEG-006, JIG-EEG-009 and
AVL-EEG-017 to **C**; FW-EEG-001 to **D**; ASM-EEG-023 and RUL-EEG-021 to **B**. **LAY-EEG-034
is new at Rev A.** 218 citations and 24 file names followed, by `tools/revision_bump.py`.

---

**Nothing in this package has been manufactured or measured. No safety engineer has reviewed
this design. No layout engineer has seen Rev C, because Rev C has no layout yet.**

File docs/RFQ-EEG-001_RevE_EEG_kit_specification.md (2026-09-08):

# Request for Quotation and Engineering Specification

Sixteen-channel research EEG instrument with co-registered audio, EMG and response channels,
streamed over an isolated USB link to a browser-based session runner.

**Document:** RFQ-EEG-001 **Revision:** E (routed four-layer production package) **Date:** 1 September 2026
**Issued by:** TI One Voice research programme (one.witysk.org), Brussels, Belgium
**Licence:** all design files CC BY-SA 4.0; firmware MIT
**Governing document:** DSN-EEG-003 Rev D. Where this document and DSN-EEG-003 differ,
DSN-EEG-003 governs. Where a number appears here and in `tools/design.py`, `design.py` governs.

**Revision note (Rev E).** Corrected to the carrier as it was actually laid out -- 150.0 × 130.0 mm
on four layers, in the enlarged POD-P1 enclosure -- and to the rulings of the cross-document audit
of 2026-09-01: E-04 restated to −80 dB, E-10 stated as ±0.5 dB with the fitted 47 kΩ and ±1.0 dB only if the
S-02 fix is taken, E-11 to ≤ 2 Hz,
F-06 to 90 s, A-03 rewritten for the chin strap and yoke, A-04 to 32 to 64 Ω, E-23's 45 °C charge
inhibit restored, E-26's button geometry restated, E-28's 2×5 header withdrawn, E-29 (maximum
acoustic output) added, and S-02, S-04, E-23 and E-27 stated plainly as not met where they are not
met.

**Corrections within Rev E (2026-09-01).** The findings of the second cross-document audit that
name this document were closed without a further revision letter: the DevKit regulator fallback
is an ECO against Rev C of the board, E-10 states the 47 kΩ and the 68 kΩ case together
everywhere, E-23 is stated as met in part, the routing result of that date and the **not
released for fabrication** status it carried replaced every claim that the board was DRC-clean
-- both are superseded by the fourth-audit paragraph below -- the ECO numbering is
restated against RUL-EEG-021 section B, and the unreconciled board-current figures are raised as
an open item. The rulings themselves are the controlled document **RUL-EEG-021 Rev B**.

**Further corrections within Rev E (2026-09-01, third audit).** Still without a revision letter: **E-11 is stated as met in part**, because the ±15 % X7R capacitors the design actually fits move the envelope corner outside the ±10 % the requirement asks for, and the note claiming that TST-EEG-004 already allowed for that is withdrawn -- the band TST-EEG-004 T12e sets is 42 to 58 Hz, measured per unit, and it is wider than E-11; **M-05 names the Peli 1560 as the settled baseline shell** on PKG-EEG-015 section 3.2's reconciled figures, so the "the shell is not selected" of the previous issue and the two disagreeing transcriptions behind it are withdrawn; and **section 12 item 14 is restated from ICD-EEG-006 section 2.7's tally** rather than from the superseded per-rail figures. Section 12 item 15 is new and carries the E-11 band.

**Fourth correction within Rev E (2026-09-02).** Still without a revision letter: **EEG-CAR-01
Rev B now closes.** `kicad/EEG-CAR-01_RevB_DRC_report.txt` reports 145 of 145 nets fully
connected, no unclosed net, no net without copper and **zero DRC violations**, and the two
electrode-clearance vias at 0.328 mm are gone with the rest. The twenty-five open items are
withdrawn wherever this document counted them, and the **not released for fabrication** status is
replaced by the status the programme actually decided: **released for review under RFQ-EEG-002A,
with fabrication release awaiting that review.** Nothing else moves. Nothing in this package has
been manufactured or measured, no human layout engineer has read the routing, and 169 of its
connections were relaxed to close. *This paragraph ended, at first issue, "and S-02, S-04, E-23 and
E-27 are exactly as not met as they were". **That sentence is superseded on 2026-09-02** by the
fifth correction below: S-02 and E-27 are met, E-11 is met in both halves, and S-04 and E-23's
45 °C-inhibit half are the two that are still not.*

**Fifth correction within Rev E (2026-09-02, after the design changes of that afternoon).** Still
without a revision letter, and this one moves requirement rows rather than status wording. **S-02
is met.** ECO-EEG-024 is applied in `tools/design.py`: R1--R16 are **68 kΩ**, not 47 kΩ, so the
single-fault DC current is 36.8 µA on the bare-resistor bound and 30.0 µA on the measuring-device
bound against the 50 µA limit, where 47 kΩ gave 53.2 µA and overshot by 6.4 %. E-10 moves onto the
**±1.0 dB** branch it already states for exactly this case, and TST-EEG-004 T22 grades against it.
**E-27 is met**: the bicolour phase driver is written. **E-11 is met in both halves**: the
Sallen-Key moved from X7R to C0G. **The firmware is built**, under ESP-IDF v5.2.5 for esp32s3, and
has been **run once under QEMU** -- and never on hardware. Section 12 is reconciled against all of
it: items 2, 4, 12 and 15 are closed or restated with the date they moved, and items 1, 3, 5 to 11,
13 and 14 are untouched and still open. **What has not changed is the important part**: nothing in
this package has been built, assembled or measured; no human layout engineer has read the routing;
no safety engineer has reviewed the design; and RISK-EEG-011 SR-01 stays **open** for the safety
reviewer's written disposition, because applying the fix an analysis recommends is not the same as
having the reviewer who owns the finding sign it off.

**Scope:** review and sign-off of the supplied carrier routing (RFQ-EEG-002A), then prototype
builds and complete field kits in three phases (RFQ-EEG-002B) -- 2 prototype units, 10 kits,
then 10 to 40 further kits (25 to 50 in total).

---

## Status of this document

This document specifies an instrument that **has not been built**. Nothing in this package has
been manufactured or measured; every figure marked *calculated* is exactly that. **No safety
engineer has reviewed this design.** Passing every test in section 9 does not, by itself, make a
unit fit to wear; the electrical safety review of section 9.2 is what releases Phase 2.

**The fabrication data is RELEASED FOR REVIEW under RFQ-EEG-002A. Fabrication release awaits
that review.** EEG-CAR-01 Rev B is routed and poured on four layers, and
`kicad/EEG-CAR-01_RevB_DRC_report.txt` reports **145 of 145 nets fully connected, no unclosed
net, no net without copper and zero DRC violations** -- in the report's own words, "the board
passes every rule listed above". ECO-EEG-016 section 3 sets the gate for releasing fabrication
data as zero violations, every net one connected copper island, and both inner planes continuous
under the analogue zone; **all three are now met**. What has not happened is the review. The
routing was produced by the programme's own tools, **no human layout engineer has looked at it**,
and 169 of its connections were relaxed to close, so the board closes at minimum geometry in
places (see the routed-result note below). RFQ-EEG-002A is that review, and it is what releases
the data for fabrication. Boards are not ordered against this issue.

Every requirement below is labelled Mandatory (M), Should (S) or Optional (O). Bidders are asked to
state compliance against each M and S requirement and to price O items separately. Where a
requirement is **not met by the design as it stands**, this document says so in the same sentence
as the requirement rather than in an annex.

**What changed in Revision D.** Rev C asked a bidder to route the carrier board. The board is
now routed and poured, and the complete fabrication package -- Gerber X2, both
Excellon drill files, an IPC-D-356A netlist, BOM with manufacturer part numbers, separate SMT
and through-hole pick-and-place files, fabrication and assembly drawings, and an eight-sheet
schematic -- is in the package. RFQ-EEG-002A is therefore re-scoped from *route this board* to
**review this routing and sign the result off**. Regenerating the board from a single machine-readable
source also found fourteen defects in Rev C's design basis, four of which made the board
unbuildable. They are listed in DSN-EEG-003 Rev D section 9 and each is logged in ECO-EEG-016.

**What changed in Revision E.** Two things changed during layout, and both are engineering
findings rather than preferences.

**The carrier grew from 130 × 124 mm to 150.0 × 130.0 mm.** Thirty connectors, 211 reference
designators and 156 nets would not close at the smaller size. At these quantities the extra 33.8 cm²
of bare board costs a few euro per unit against a real risk of an unroutable design.

**The carrier went from two layers to four.** Package v1's architecture argument was that a
two-layer carrier is cheap and easy to route. Actually laying it out showed that it is not: on two
layers the bottom side has to be both the reference plane and the second routing surface, and it
cannot be both. Four layers -- **L1 signal, L2 reference plane, L3 reference plane, L4 signal** --
give two full routing surfaces and a continuous reference under every analogue trace, which is what
DSN-EEG-003 Rev D section 3.3 asks for and which a swiss-cheesed two-layer pour cannot deliver. The
reference planes carry **AGND_REF left of x = 62 mm and DGND right of it, on both L2 and L3**, tied
together by stitching vias. Vias are **through vias only**, 0.60 mm pad on a 0.30 mm finished hole;
no blind, buried, back-drilled, filled or plugged vias are used. The stack-up is mask / 35 µm L1 /
prepreg 0.200 / 17 µm L2 / core 1.065 / 17 µm L3 / prepreg 0.200 / 35 µm L4 / mask = **1.60 mm
± 10 %**. At 2 units the fourth and third layers cost about €35 in total; at 50 units about €3 per
board. That is the right trade for a sixteen-channel EEG front end, and section 10 now carries a
four-layer fabrication line.

**The routed result, from `kicad/EEG-CAR-01_RevB_DRC_report.txt`.** EEG-CAR-01 Rev B is routed on
four layers, 150.0 × 130.0 mm, with **3 745 track segments and 552 through vias**. **All 145 nets
are fully connected**; none is unclosed and none is without copper; and each inner plane is **one
continuous copper island per net** on both In1.Cu and In2.Cu. Every geometric rule in the report
passes: the smallest measured clearance is 0.260 mm on F.Cu, 0.275 mm on B.Cu and 0.285 mm on
both planes against a 0.20 mm rule; the narrowest conductor is 0.20 mm; the smallest plated hole
is 0.30 mm; copper stands 2.00 mm off every non-plated hole; zero digital nets enter the analogue
zone; and there is exactly one AGND_REF-to-DGND bridge and exactly one HARN_SHIELD-to-DGND
bridge. There are no duplicate track segments and no duplicate via positions. The report records
no clearance, width, annular-ring, hole-size, board-edge, non-plated-hole, isolation-keep-out or
via-keep-out violation, so the isolation strip is clean on all four copper layers -- stated here
because the report says it, not because the rule was asserted. **VIOLATIONS: 0.** The two vias
that sat 0.328 mm from an electrode net in the previous routing are gone.

**What the report does not say is that the routing is good.** It closes, and in places it closes
at minimum geometry: **169 connections were relaxed to make them** -- 36 took a conductor
narrower than the 0.25 mm preferred width, and 133 kept full width and took a reduced gap
instead. All 169 are at or above the 0.20 mm minimum conductor and the 0.20 mm minimum gap, and
0.35 mm on electrode nets, so every one of them passes; they are listed pad to pad in the report
so that a reviewer can see exactly where the router had to squeeze. A board that closes at
minimum geometry is not the same board as one that closes at preferred geometry, even when every
rule passes. That judgement, and the fact that **no human layout engineer has read this
routing**, is what RFQ-EEG-002A buys. **The data is released for review under it; fabrication
release waits on the review.**

The enclosure grew with the board: POD-P1 is now 163.0 × 143.0 × 58.0 mm external and
158.0 × 138.0 × 55.5 mm internal, and the MP-01 module plate is 146.0 × 126.0 × 3.0 mm.

**ECO numbering**, as ruled in RUL-EEG-021 section B. The change *register* is the document
ECO-EEG-016. The individual changes are ECO-EEG-001 to ECO-EEG-015, ECO-EEG-017 and
ECO-EEG-018, so that no change shares a number with the register: the routing-scope change that
once carried the number ECO-EEG-016 is now **ECO-EEG-018**, and both layout findings above -- the
growth to 150.0 × 130.0 mm and the move from two layers to four -- sit inside it. A Rev B
draft of ECO-EEG-016 briefly numbered those two findings separately, as ECO-EEG-028 and
ECO-EEG-029; **both numbers are withdrawn**, and the findings sit inside ECO-EEG-018.
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

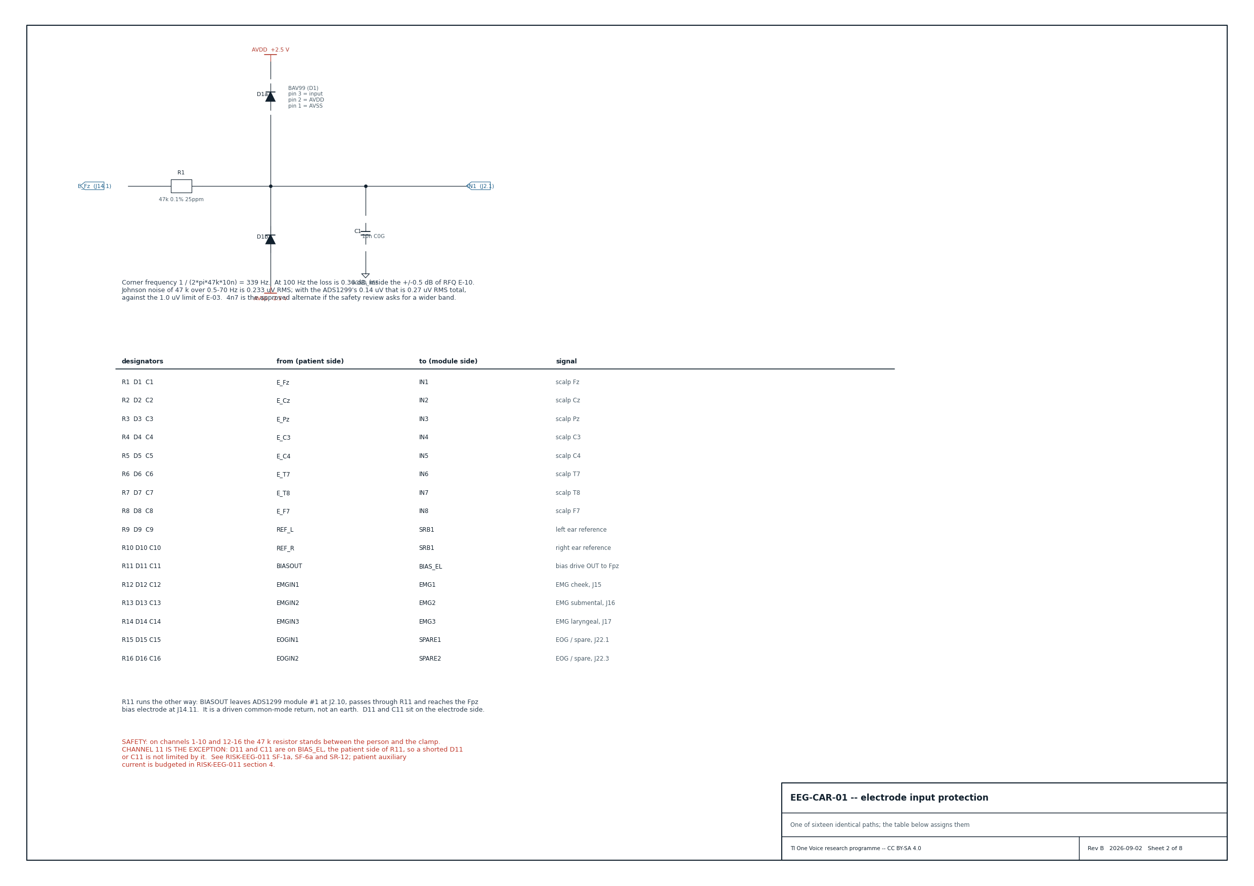
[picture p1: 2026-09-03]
schematic/png/sheet2_protection.png

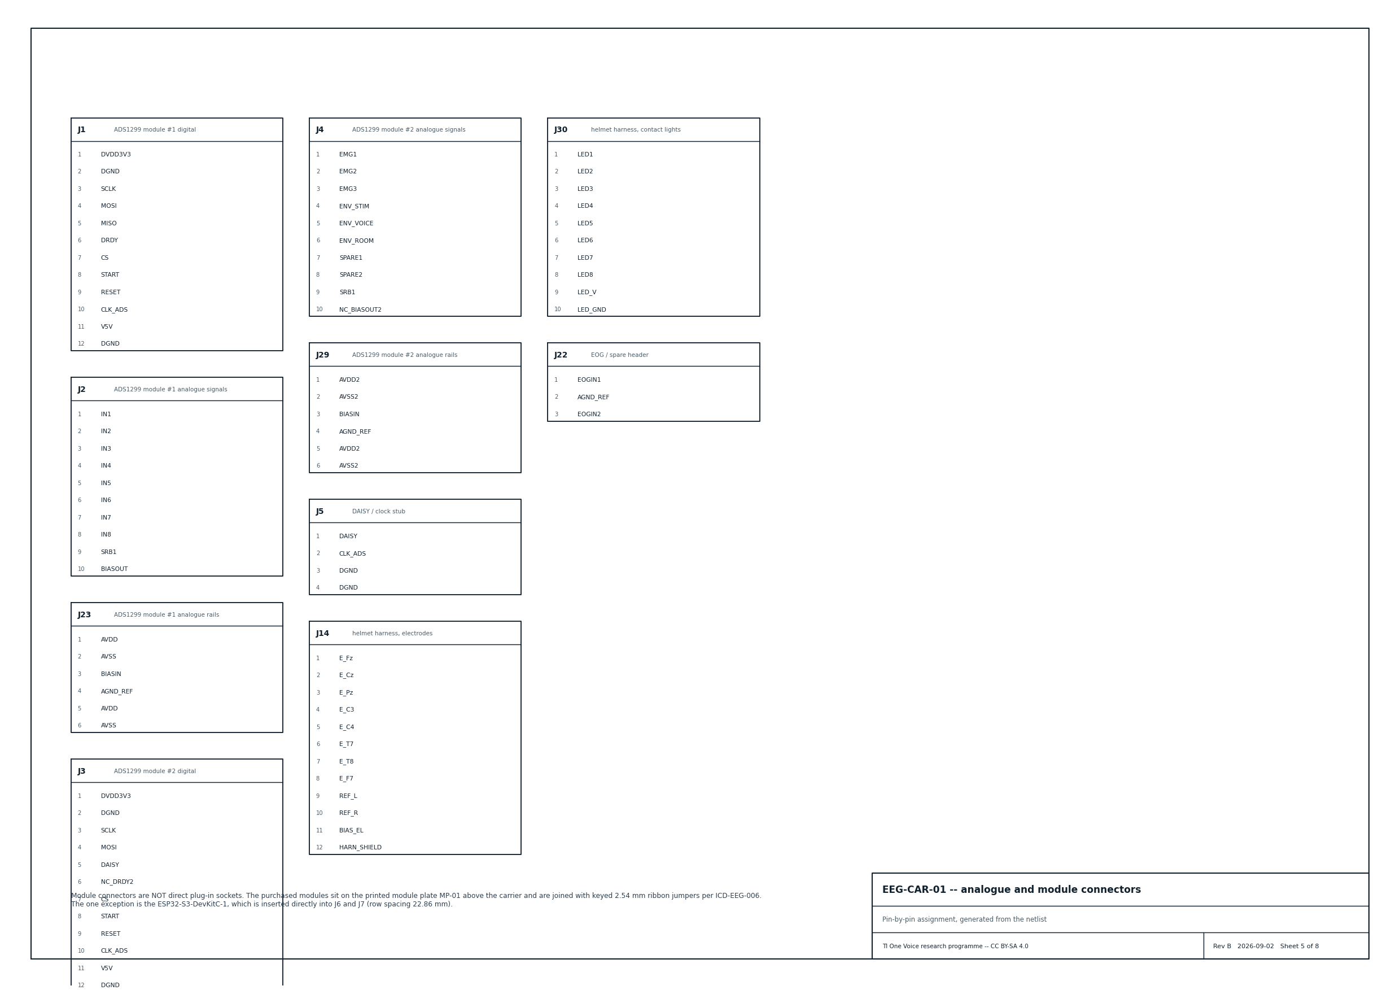
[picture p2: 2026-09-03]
schematic/png/sheet5_connectors.png

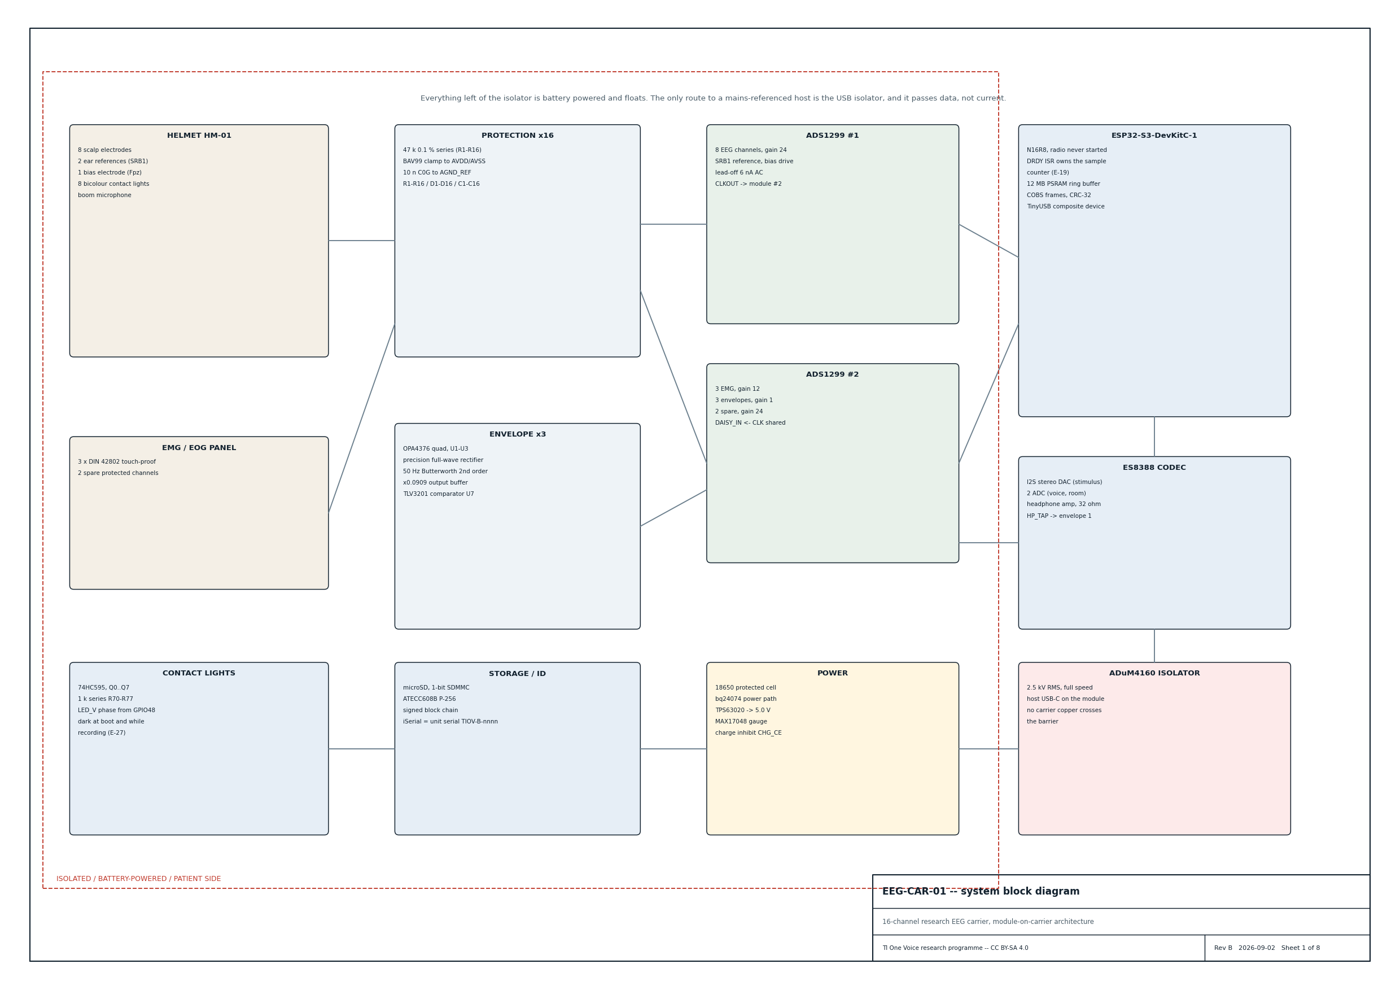
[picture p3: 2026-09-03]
schematic/png/sheet1_block.png

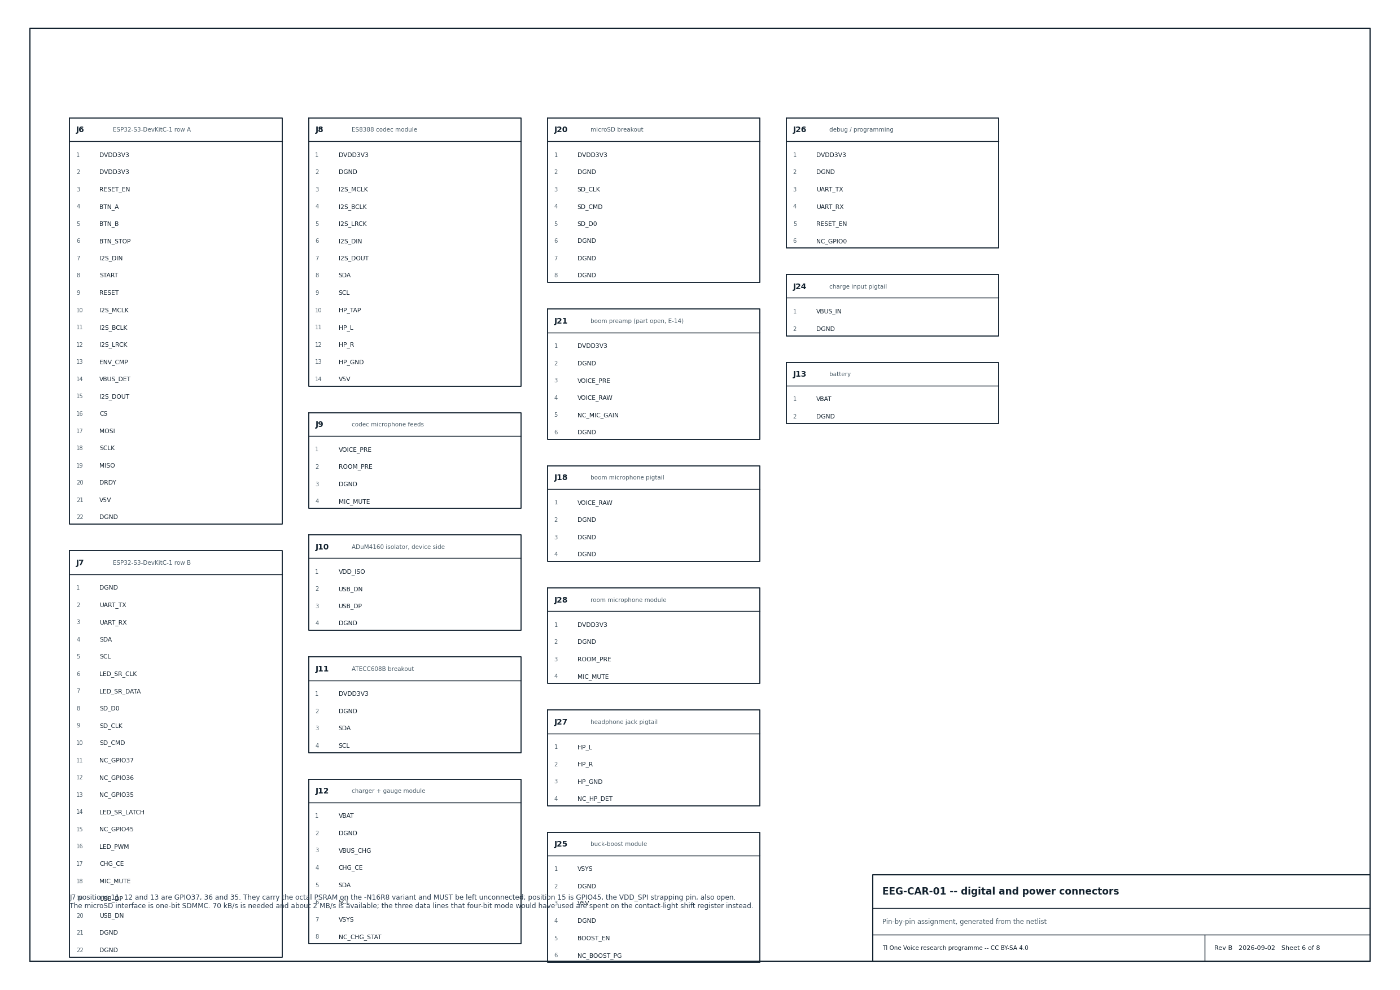
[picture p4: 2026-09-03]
schematic/png/sheet6_connectors.png

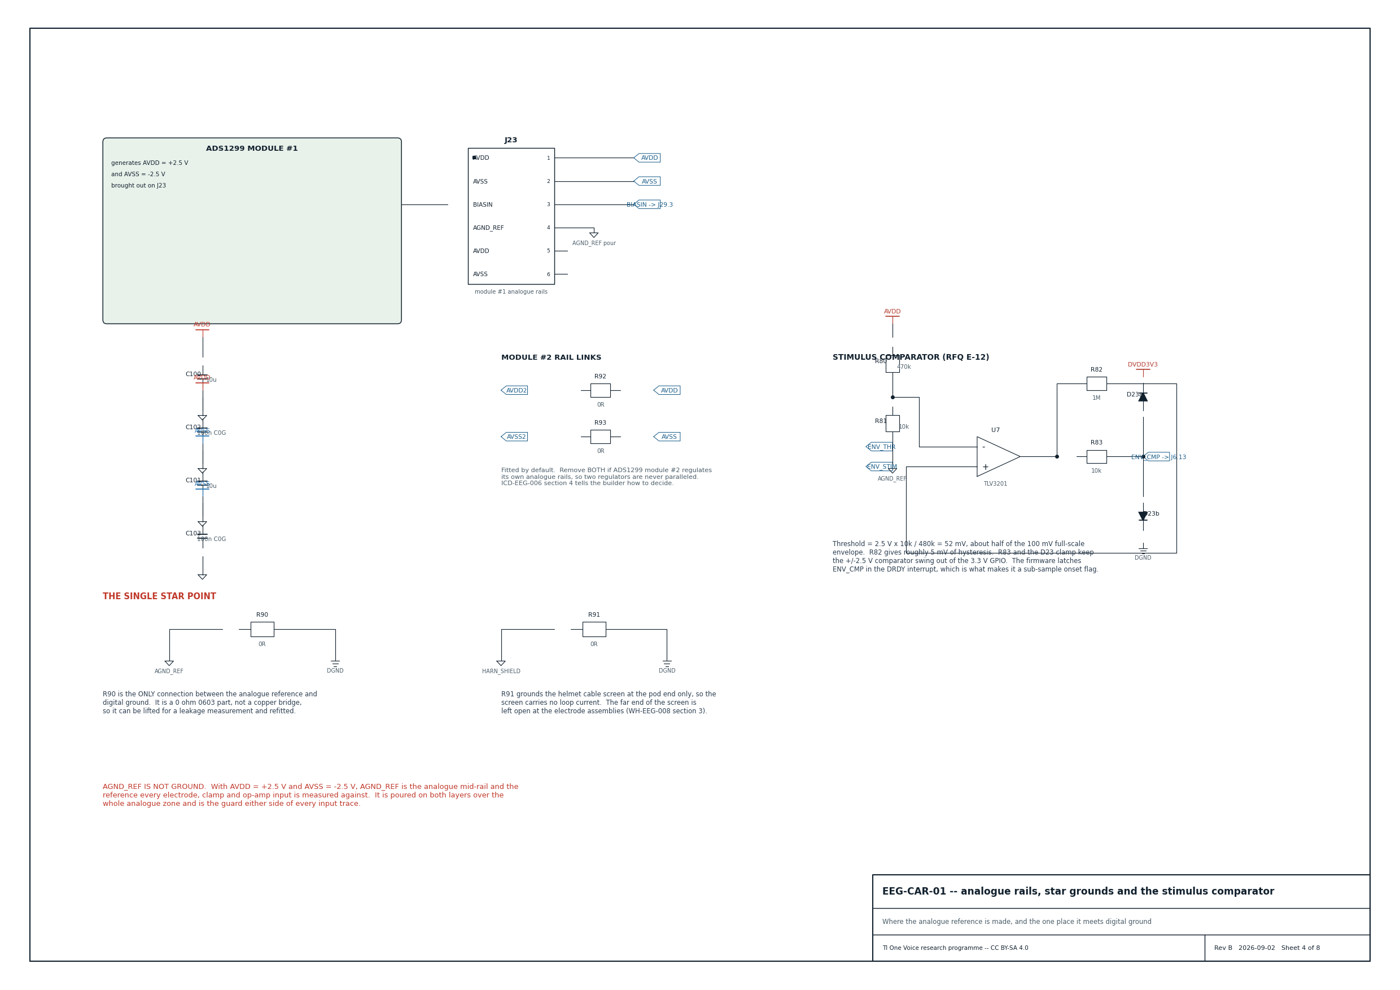
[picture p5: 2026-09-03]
schematic/png/sheet4_rails.png

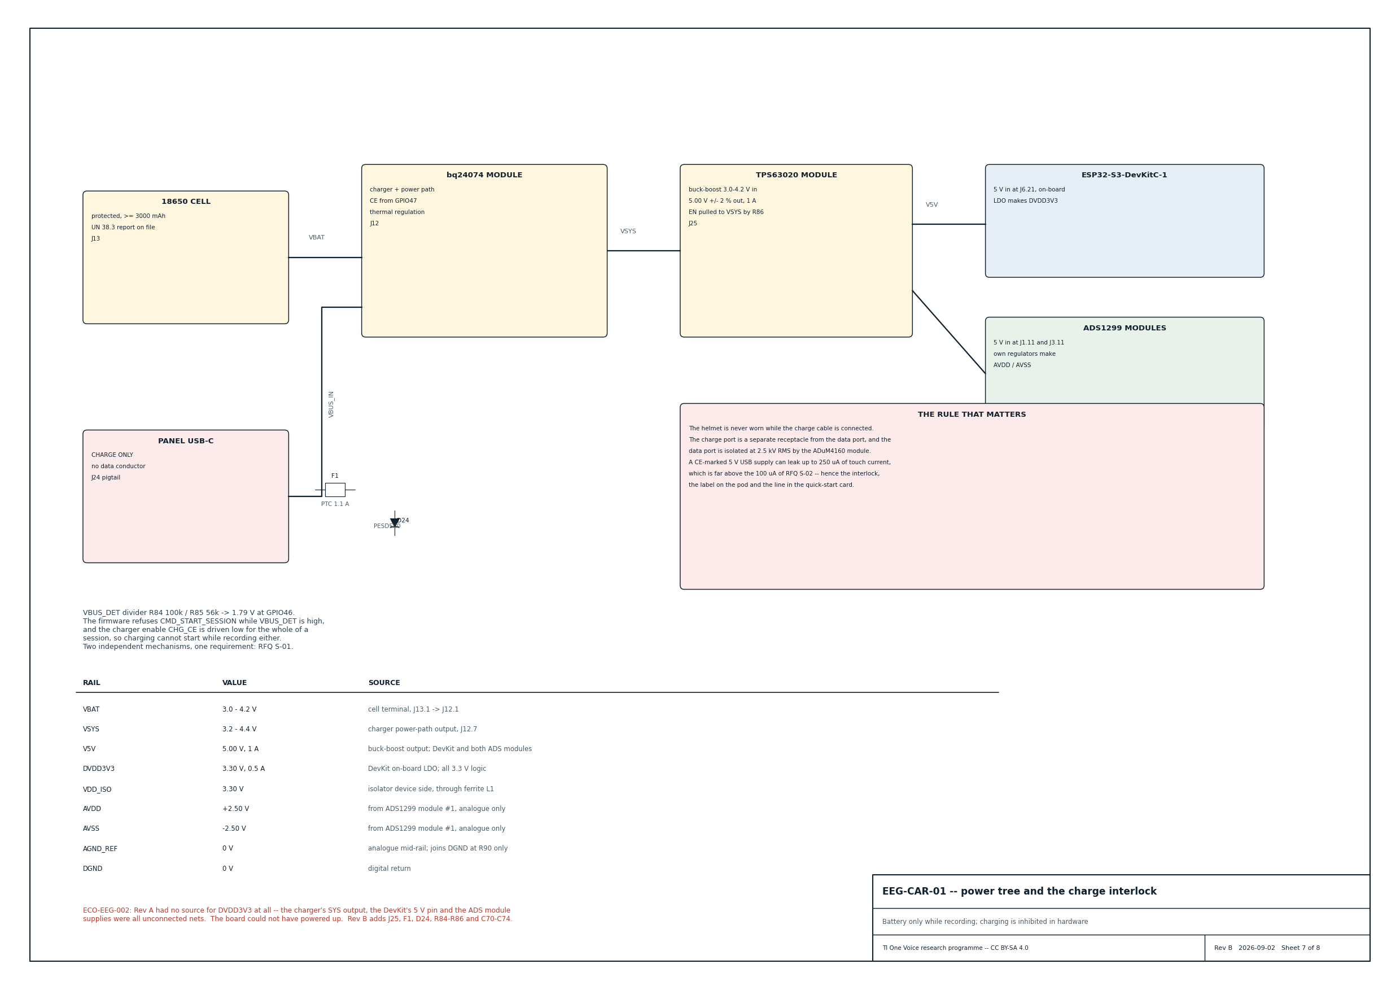
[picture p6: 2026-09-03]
schematic/png/sheet7_power.png

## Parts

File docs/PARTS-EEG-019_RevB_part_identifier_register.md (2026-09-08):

# PART IDENTIFIER REGISTER

**Document:** PARTS-EEG-019  **Revision:** B  **Date:** 2026-09-01
**Issued by:** TI One Voice research programme (one.witysk.org), Brussels, Belgium
**Licence:** CC BY-SA 4.0
**Governing documents:** DSN-EEG-003 Rev D, then RFQ-EEG-001 Rev E. Where this
document and design.py disagree, design.py governs.

**Revision note, Rev A to Rev B.** Re-issued against the 150.0 x 130.0 mm four-layer
carrier and the enlarged POD-P1 and MP-01: every bounding box and volume in section 2 is
regenerated from the released `tools/mech_gen.py` meshes, WH-08 is withdrawn and WH-09,
WH-KEY-01, WH-BUS-01 and the five WH-ADP adapters are registered, the unit serial format
is settled as `TIOV-B-nnnn`, and the duplicated foam-pocket and fixture-step lists are
replaced by cross-references.

**The findings of the second cross-document audit that name this register are closed in
this issue, within Rev B and without a further revision letter**: the layout-rule citation
is corrected to DSN-EEG-002 section 13 and DSN-EEG-003 section 3.3, the fixture
sub-assembly names and the fixture-to-step citations are aligned to TST-EEG-004 Rev C
section 6.1, the MP-01 slot figure is restated as a slot size taken from
`tools/mech_gen.py`, and RUL-EEG-021 is recorded as a document identifier.

**Also within Rev B and without a further revision letter (2026-09-02):** the EEG-CAR-01 row in
section 2.4 is restated against the re-routed board. `kicad/EEG-CAR-01_RevB_DRC_report.txt` now
records 145 of 145 nets fully connected and **zero DRC violations**, so the twenty-five open
items and the two electrode-clearance vias at 0.328 mm are withdrawn from that row, and the
fabrication data is **released for review under RFQ-EEG-002A, with fabrication release awaiting
that review**. What has not changed: the routing has still not been read by a human layout
engineer, 169 of its connections were relaxed to close, and no board has been fabricated.

**Also within Rev B and without a further revision letter (2026-09-02), after the independent
review of package v2.2:** section 2.3 is re-registered against what `mech/` actually holds. The
two Rev B foam files this register named are withdrawn and deleted; the seven CASE-00 **Rev C**
layer files are shipped, and CASE-00-03 to CASE-00-07 are registered here for the first time.
The register had been carrying two layers against a seven-layer part, and pointing a foam cutter
at two filenames that no longer exist. OA-8 is closed by the Rev C bay, and the honest part of
it survives in section 2.3: the seven files are drawn and **not released for cutting**.

**Also within Rev B and without a further revision letter (2026-09-02), after the design and
firmware changes of that day:** the EEG-CAR-01 row in section 2.4 no longer says that 47 kΩ
is fitted and S-02 is not met -- **ECO-EEG-024 is applied, R1-R16 are 68 kΩ and S-02 is met
at 36.8 µA on the calculation**, with the safety sign-off still owed -- and the FW-EEG-001 and
FIX-01 rows in section 2.5 no longer say the firmware has never been compiled or that the
contact-light phase driver does not exist. **The firmware is built and the driver is written.**
Neither has run on hardware, no unit exists, and T11 has not been run.

**A note on DSN-EEG-002 Rev E, which this register cites throughout.** It has not been
re-issued since package v2.1 and the shipped file is byte-identical, so its **sections 7, 10
and 11** are cited here for geometry, materials and fitting only, and are **superseded on three
points**: section 10's `HM-07` / `HM-08` part numbering is superseded by sections 3.1 and
3.2 of this register (HM-08 is the battery hatch, HM-10 the keyed cell carrier, HM-07A/B/C the
boom arm), and section 7's "a charged spare travels in the case" is superseded by
REG-EEG-012 Rev B section 3.1 and RISK-EEG-011 Rev B section 6.1, which record zero spare cells
in circulation. Its **section 11** travel-case figure, FIG-19 in the map of section 3.3 below,
draws the two-layer foam and is superseded by the CASE-00 Rev C schedule of PKG-EEG-015
section 2.2 and by section 2.3 above. ECO-EEG-016 section 1.1 records the file as "released,
not reissued in this round"; its re-issue is an open document action, not a decision still to
be taken.

**Also within Rev B and without a further revision letter (2026-09-02), after the completeness
audit of package v2.3: twelve printed parts are re-registered from "to be created" to
"exists".** HM-02B, HM-02C, HM-03A, HM-05B, HM-10, HM-11A, HM-11B, HM-11C, POD-P1-04,
WH-ADP-02, WH-ADP-03 and WH-ADP-04 all have STL, STEP, a MECH-EEG-020 sheet and a
`mech/MANIFEST.json` entry, and all three WH-KEY-01 forms do too; the register was telling a
shop that parts sitting in `mech/stl/` did not exist. Their model figures are read from the
released meshes, the MECH-EEG-020 sheet numbers throughout §2 are corrected against
`mech/drawings/MECH-EEG-020_sheet_index.csv` -- the set is now 25 sheets, not 10 -- and
AVL-EEG-017 K24 names them so a print bureau can quote them. **WH-BUS-01's entry is corrected
on both counts WH-EEG-008 open item 15 raised**: it is a two-layer board, and its Gerber,
drill, netlist and README set exists in `kicad/wh-bus-01/`. POD-P1-01's volume is restated at
144.42 cm³ from the released mesh. Two new identifiers, **HM-04A** and **HM-05C**, are
registered for the halves of the HM-04 electrical termination that WH-EEG-008 §3.1.1 proposes,
and both are marked PROPOSED rather than allocated to a released part -- OA-14, OA-15 and
OA-16. **The seven printed fixture solids released in `fixtures/` are registered in §2.4 for the
first time**, named by their TST-EEG-004 §6.1 sub-assembly letter and their filename, because
this register allocates none of that letter set itself -- OA-17.

**Also within Rev B and without a further revision letter (2026-09-02), after the design changes
of 2 September 2026.** Two released helmet parts were re-cut, a bought-in class of connector
arrives in the register for the first time, and one harness number is reserved. **HM-04 and HM-05B now assemble.** The pair as
released did not: the HM-05B lug stood at an outer radius of 5.40 mm against a 5.30 mm slot --
0.10 mm of radial interference and zero tangential clearance -- and `hm04()` cut two straight
axial slots with no circumferential run behind them, so the carrier could not enter and, if it
had, could not turn. The lug is corrected to 5.20 mm, which is what `hm05b()`'s own docstring has
always said, and raised to z 1.20--3.30; the entry slots are 1.70 mm wide at an outer radius of
5.55 mm and 3.60 mm deep; and HM-04 gains a **100° circumferential run at z 1.10--3.80 with
1.10 mm of retaining lip below it**. `tools/simulate_production.py` measures the two solids at four
rotations and three axial positions on every run and reports 0.000 mm³ through the quarter turn,
0.000 mm³ through the carrier's 0.40 mm of spring travel and 1.557 mm³ of lip engagement when the
seated carrier is pulled down. **HM-04's contact-light window is now two pockets** with 1.60 mm of
printed PA12 between them, an outboard LED seat and an inboard conductor run, where it was one box
straight through the body -- the arrangement RISK-EEG-011 SF-9 describes. **HM-04's spring seat is
6.60 mm deep**, not 4.50, which takes the free height above the HM-05B spigot from 1.40 mm to
3.50 mm. The model figures of both parts move with all of this and are restated in §2.1 from the
released meshes; **both parts are owed a revision letter** under rule 5 of §1.3, and the deepened
seat is in `tools/mech_gen.py` and not yet in a released mesh -- OA-18. Separately, **WH-10 is
reserved** for the Fpz bias lead, and the 1.5 mm touch-proof DIN 42802-1 sockets for the two ear
references and for the bias lead are registered in §2.4 as bought-in parts that take no identifier
under rule 4 -- OA-16, extended, and OA-19. Nothing here has been printed, and every one of these
changes is a change to a source file and a mesh, not to a part.

**Nothing in this package has been manufactured or measured, and no safety engineer has
reviewed this design.** Every dimension, volume and mass in this register is calculated
from a released model file. No part has been printed, no board has been fabricated, and the
first thing Phase 1 does is find out which of these figures are wrong.

## Why this document exists

Package v1 used the code `HM-xx` for two different things at once: as figure labels in
DSN-EEG-002 Rev E and as part numbers in the same document's section 10. Only `HM-01`
happened to mean the same thing in both. The consequence was not cosmetic. `HM-07` named
the boom microphone arm in DSN-EEG-002 section 10 and the battery hatch in DSN-EEG-003
section 4, in `mech/HM-07_battery_hatch.stl`, in `mech/MANIFEST.json`, in kit BOM item 17
and in the RFQ Rev C scope line -- so a contract manufacturer printing "HM-07" produced a
gooseneck arm or a quarter-turn hatch depending on which document was open, and whichever
one was printed, the other part was silently dropped from the kit. DSN-EEG-002 section 10
also requires part IDs to be engraved into the model, so the wrong identifier would have
been moulded into the part. This register fixes one identifier for each part in the
package, states which file defines it and which document specifies it, and is cited by
every other document in package_v2.3 (DSN-EEG-003 Rev D Annex A lists it sixth in the
precedence order). It closes contradictions XD-01, XD-02 and XD-03 and gaps
`mech-hm07-part-number-conflict` and `mech-missing-part-files`.

Rev B exists because the geometry moved underneath the register. Two findings came out of
actually laying the carrier out instead of asserting that it would lay out, and both
propagate into every printed part this document names.

**The carrier grew from 130 x 124 mm to 150.0 x 130.0 mm.** Thirty connectors, 211 parts
and 156 nets would not close at the smaller size. At Phase 1 and Phase 2 quantities the
extra 33.8 cm2 of bare board costs a few euro per unit against a real risk of an unroutable
design, so the board grew.

**The carrier went from two layers to four.** Package v1's architecture argument was that a
two-layer carrier is cheap and easy to route. Doing the layout showed that it is not: on
two layers the bottom side has to be both the reference plane and the second routing
surface, and it cannot be both. Four layers -- L1 signal, L2 reference plane, L3 reference
plane, L4 signal -- give two full routing surfaces and a continuous reference under every
analogue trace, which is what DSN-EEG-002 section 13's "layout rules that are requirements,
not preferences" require, and what the zoning, star-point and isolation rules of
DSN-EEG-003 section 3.3 require, and which a swiss-cheesed two-layer pour cannot deliver.
The two citations are not interchangeable: DSN-EEG-002 section 13 carries the layout rules
that are requirements, and DSN-EEG-003 has sections 1 to 11 plus annexes and no section 13,
so a reference to "DSN-EEG-003 section 13" is stale and is corrected to one of these two.
At 2 units the four-layer board is about EUR 35 more in total; at 50 units it is about
EUR 3 per board.

The enclosure and the module plate grew with the board, and MP-01, POD-P1-01 and POD-P1-02
are therefore at new revisions in this issue. The change is recorded against EEG-CAR-01 in
section 2.4 and in the migration table of section 3.2.

---

## 1. Naming rules

### 1.1 Four namespaces, never mixed

| Namespace | Form | Owner | Example |
|---|---|---|---|
| Part identifiers | `<PREFIX>-nn`, optional letter suffix for a member of an assembly | this document | `HM-08`, `HM-02A` |
| Document identifiers | `<TYPE>-EEG-nnn Rev X` | ECO-EEG-016 | `DSN-EEG-002 Rev E` |
| Requirement identifiers | `E-nn`, `F-nn`, `A-nn`, `M-nn`, `S-nn`, `O-nn` | RFQ-EEG-001 Rev E | `M-05`, `S-09` |
| Reference designators | `R`, `C`, `D`, `J`, `L`, `F`, `U`, `SW`, `TP`, `FID`, `MH` + number | `tools/design.py` | `J14`, `R90`, `TP13`, `FID2`, `MH1` |
| Figure labels | `FIG-nn` | the document that carries the figure | `FIG-18` |

`TP` and `FID` are in the designator list because Rev B of the carrier has eighteen test
points (TP1 to TP18, RFQ E-28) and three global fiducials (FID1 to FID3, ECO-EEG-020) that
Rev A of this register did not list. They are reference designators owned by `design.py`,
not part identifiers, and no fiducial or test point is ever given an `HM`, `POD` or `MP`
number.

A figure label must never begin with a part prefix. This is the rule that XD-02 exists to
create: in package v1 the caption "HM-07 -- the frame unmounted" and the part "HM-07 boom
microphone arm" sat eleven lines apart in the same section. Figures are numbered `FIG-01`
upward in document order within each document, and are cited from outside as
`DSN-EEG-002 FIG-18`. Section 3.3 gives the full v1-to-v2 figure map for DSN-EEG-002.

**The document namespace is ECO-EEG-016's, and it currently has the same fault this
register was written to fix for parts.** The package cites as governing or required about
nineteen document numbers that are not on the ECO-EEG-016 section 1 register, and six of
them collide numerically with registered documents -- REL-EEG-009 against JIG-EEG-009,
PROV-EEG-007 against ASM-EEG-007, KEY-EEG-008 against WH-EEG-008, SD-EEG-013 against
SVC-EEG-013, OTA-EEG-014 against IFU-EEG-014 and CAL-EEG-012 against REG-EEG-012. That is
not this register's namespace to repair and it is recorded here only as OA-11, against
ECO-EEG-016. Two of the numbers that were unregistered when Rev A was written are now on
that register: **RUL-EEG-021**, the rulings register, and **SIM-EEG-018**, the production
simulation report, both at Rev A in `docs/`.

**RUL-EEG-021 is a document identifier and never a part identifier.** It is a controlled
document on the ECO-EEG-016 section 1 register, it takes the `<TYPE>-EEG-nnn Rev X` form of
row 2 of the table above, and it is cited as **RUL-EEG-021 with a section letter** -- for
example RUL-EEG-021 section A for the geometry rulings and section B for the instrument
rulings. No `RUL` prefix exists in the part namespace of section 1.2, no `RUL` number is
ever allocated to a printed, bought-in or fabricated item, and nothing in section 2 of this
register carries one. SIM-EEG-018 is read the same way: a document number, and a record
rather than a specification.

### 1.2 Prefixes and number ranges

| Prefix | Covers | Range | Allocated | Reserved for |
|---|---|---|---|---|
| `HM` | Helmet: frame, pads, fixation, electrode assemblies, hatch, key, cell carrier, channel covers | HM-01 to HM-19 | HM-01 to HM-11 | HM-12 to HM-19, Phase 2 |
| `POD` | Electronics enclosure and its fittings. Phase variant in the identifier: `-P1` bench, `-H2` in-helmet | POD-P1-01 to -19, POD-H2-01 to -19 | POD-P1-01 to -05 | Phase 2 occipital shell |
| `CASE` | Travel case, foam, packing printed matter | CASE-00 (foam family, historic), CASE-01 to CASE-09 | CASE-00-01 to -07, CASE-01 to -03 | CASE-04 to -09 |
| `MP` | Module plate and its hardware | MP-01 to MP-09 | MP-01 | plate variants |
| `WH` | Cable and harness assemblies, and their named sub-assemblies | WH-01 to WH-19, plus `WH-KEY-nn`, `WH-BUS-nn`, `WH-ADP-nn` | WH-01 to WH-07, WH-09; **WH-10 reserved and not issued** (Fpz bias lead -- §2.4, OA-19); WH-KEY-01, WH-BUS-01, WH-ADP-01/-01B/-02/-03/-04 | Phase 2 umbilicals |
| `EEG-CAR` | Carrier printed circuit board | EEG-CAR-01 to -09 | EEG-CAR-01 | EEG-CAR-02/-03, the Phase 2 split boards |
| `FIX` | Production test fixtures, and their own printed parts as `FIX-nn-mm` | FIX-01 to FIX-19 | FIX-01 to FIX-04 | further stations |
| `FIT` | Fit-test and process coupons | FIT-01 to FIT-09 | FIT-01 | collar and lug coupon |
| `FW` | Firmware images and host tools | `FW-EEG-nnn` | FW-EEG-001 | host tools |

`FIT` is a ninth prefix, not in the original scheme. It is here because
`mech/stl/FIT-01_fit_test_coupon.stl` was released before this register and
`tools/mech_gen.py` governs the filename; inventing a tenth name for a file that already
exists would recreate the fault this document is closing.

**The three `WH` sub-forms are the one exception to the `<PREFIX>-nn` rule**, and they are
here for the same reason `FIT` is: WH-EEG-008 Rev B already uses `WH-KEY-01`, `WH-BUS-01`
and `WH-ADP-01` to `WH-ADP-04` in its wire lists, its build order and its test record, and
renaming them into the plain `WH-nn` run would put a keying shroud and a cable in the same
number series and invite exactly the confusion described above. The sub-form is read as
"WH namespace, `KEY` / `BUS` / `ADP` family, member nn". No `WH-nn` cable number is ever
reused for a sub-assembly and no sub-assembly number is ever shortened to `WH-nn`.

**WH-08 is withdrawn and its number is not reused.** It named a captive 2 m host USB-C lead
leaving the pod through a Lapp SKINTOP gland. The host connection is a socket, not a captive
cable, so WH-08 and the gland are deleted from the Phase 1 build; see section 2.4 and
WH-EEG-008 Rev B section 1.

### 1.3 Rules of use

1. **One identifier, one part.** If two things can be ordered, printed, inspected or
   scrapped separately, they are two parts and they get two identifiers.
2. **The filename begins with the identifier.** `HM-08_battery_hatch.stl` is HM-08. The
   two exceptions are the POD-P1 and CASE-00 families, whose filenames carry the family
   token and whose members are distinguished by the descriptive tail; the register table
   in section 2 gives the mapping explicitly for those four files.
3. **A letter suffix means a member of a named assembly**, not a revision. `HM-02A` is the
   brow pad; the revision of HM-02A is carried in its own column and is never written into
   the identifier.
4. **Bought-in catalogue items get no identifier** unless the programme modifies them or a
   printed interface part exists for them. An unmodified Nanuk case, an Ambu snap pad or a
   Panasonic cell is identified by its supplier part number and its AVL-EEG-017 line. The
   ratchet mechanism, the gooseneck and the sintered cup *are* modified or mated to printed
   parts, so they carry identifiers.
5. **A revision letter belongs to the part, not to the package.** Any change to a released
   file raises the letter. HM-04 and HM-08 are at Rev B because their models were rebuilt
   parametrically; MP-01, POD-P1-01 and POD-P1-02 are at Rev B because the carrier grew and
   they were resized to match. Neither is because the package revised.
6. **Nothing in this register has been manufactured.** Every dimension and volume quoted is
   calculated from the released mesh, not measured on a part.

---

## 2. The register

Bounding boxes and volumes are calculated from the released STL in
`package_v2.4/mech/stl/` (bounding box from the vertex extremes, volume by the divergence
theorem over the closed mesh). They are model figures. No part has been printed, so no
figure here has been verified against hardware.

### 2.1 Helmet, prefix HM
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

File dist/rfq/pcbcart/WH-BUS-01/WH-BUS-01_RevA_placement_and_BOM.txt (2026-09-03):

WH-BUS-01 Rev A -- placement and BOM note
generated 2026-09-01 from package_v2.4/tools/wh_bus.py

BOM

  Nothing is fitted to this board.  It carries no resistor, no capacitor, no diode, no
  connector and no fiducial, and there is no CPL file, no paste layer and no stencil,
  because there is no part to place.  The kit BOM line for WH-BUS-01 is the bare board:

    part        qty/kit  description
    ----------- -------- ------------------------------------------------------------
    WH-BUS-01      1     Bare PCB, 14.0 x 10.0 x 0.80 mm, 2 layers, FR-4, ENIG,
                         green mask, white legend both sides, per this data set

  The eight LED series resistors are R70 to R77 on the CARRIER, 1 kOhm each, and the two
  0 ohm links in the common are R78 and R79, also on the carrier (WH-EEG-008 section 3.2).
  Putting a resistor here would add a second limit to the same loop and change the 1.3 mA
  per site that WH-EEG-008, ICD-EEG-006 and TST-EEG-004 all quote.  Do not fit one.

PAD MAP  (fabrication coordinates: origin bottom-left, Y up, millimetres)

  pad  net          x      y   pad  sh hole   what lands on it
  ---- -------- ------ ------ ----- --- ----  --------------------------------------------
   1   LED_V      4.50   7.40  1.60 rd  0.80   tail WH-02T-1 to the Fz LED, lead B
   2   LED_V      7.20   7.40  1.60 rd  0.80   tail WH-02T-2 to the Cz LED, lead B
   3   LED_V      9.90   7.40  1.60 rd  0.80   tail WH-02T-3 to the Pz LED, lead B
   4   LED_V     12.60   7.40  1.60 rd  0.80   tail WH-02T-4 to the C3 LED, lead B
   5   LED_V      4.50   2.60  1.60 rd  0.80   tail WH-02T-5 to the C4 LED, lead B
   6   LED_V      7.20   2.60  1.60 rd  0.80   tail WH-02T-6 to the T7 LED, lead B
   7   LED_V      9.90   2.60  1.60 rd  0.80   tail WH-02T-7 to the T8 LED, lead B
   8   LED_V     12.60   2.60  1.60 rd  0.80   tail WH-02T-8 to the F7 LED, lead B
   9   LED_V      1.80   7.40  1.60 sq  0.80   WH-02 conductor 9, GY/BK, LED_V from J30.9
  10   LED_GND    1.80   2.60  1.60 rd  0.80   WH-02 conductor 10, BK, LED_GND, J30.10

  Pad 9 is square.  That is the only orientation feature on the board: square pad and the
  "9" legend mark the WH-02 input end, which faces occipital entry OE-2.  Fitted the other
  way round the eight tails still reach their LEDs, but the input pair arrives across the
  whole board and the cover strip will not close over the crossing conductors.

  Pad 10 is an island.  It is 1.10 mm from the nearest LED_V copper on both layers and is
  connected to nothing, on either layer, by design: LED_GND is a 0 V guard conductor laid
  in the centre of the WH-02 bundle and it must not become a return path (WH-EEG-008
  section 3.2 and open item 9).  If an ECO ever ties LED_GND to something, the tie is a
  wire link from pad 10, not a new board.

  The eight tails are numbered in WH-02 conductor order, so pad n feeds the second lead of
  the LED whose first lead is WH-02 conductor n.  All eight leave through the same N1 cover
  strip, so the pad order does not constrain the route inside the frame; it exists so that
  a mis-landed tail is visible against the wire list rather than only at the light.

HOW IT IS FITTED

  Hand-soldered, temperature-controlled iron at 320 C, no-clean flux, per WH-EEG-008
  section 8 step 12.  Strip 4.0 mm, tin, feed through from the legend side, solder on both
  sides.  The board is retained by the N1 cover strip and by its own ten solder joints.

  No mounting hole is specified and none is drilled.  There is also no pocket for this
  board in the HM-01 geometry, so where exactly it beds at N1 is not yet defined by any
  drawing -- that is an open item against the mechanical package, not something this data
  set can settle.

PANEL AND DELIVERY

  Supplied as a 5 x 4 V-scored array, 20 up, step 14.0 x 10.0 mm, with 5 mm rails on all
  four sides: panel 80.0 x 50.0 mm. One panel is the whole Phase 1 and Phase 2 buy, 2
  units plus 10 kits, with eight spares. See the README for the alternative if the
  fabricator will not V-score 0.80 mm material.

MEASURED FROM THIS GEOMETRY

  minimum copper to board edge      0.60 mm
  minimum LED_V to LED_GND          1.10 mm
  annular ring                      0.40 mm
  minimum legend to mask opening    0.17 mm

  These four are computed by wh_bus.py --check from the same numbers that produced the
  Gerbers.  Nothing on this board has been fabricated, soldered or measured.

Licence: CC BY-SA 4.0.

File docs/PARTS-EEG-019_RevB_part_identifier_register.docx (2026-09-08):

# PART IDENTIFIER REGISTER

Document: PARTS-EEG-019 Revision: B Date: 2026-09-01 Issued by: TI One Voice research programme (one.witysk.org), Brussels, Belgium Licence: CC BY-SA 4.0 Governing documents: DSN-EEG-003 Rev D, then RFQ-EEG-001 Rev E. Where this document and design.py disagree, design.py governs.

Revision note, Rev A to Rev B. Re-issued against the 150.0 x 130.0 mm four-layer carrier and the enlarged POD-P1 and MP-01: every bounding box and volume in section 2 is regenerated from the released tools/mech_gen.py meshes, WH-08 is withdrawn and WH-09, WH-KEY-01, WH-BUS-01 and the five WH-ADP adapters are registered, the unit serial format is settled as TIOV-B-nnnn, and the duplicated foam-pocket and fixture-step lists are replaced by cross-references.

The findings of the second cross-document audit that name this register are closed in this issue, within Rev B and without a further revision letter: the layout-rule citation is corrected to DSN-EEG-002 section 13 and DSN-EEG-003 section 3.3, the fixture sub-assembly names and the fixture-to-step citations are aligned to TST-EEG-004 Rev C section 6.1, the MP-01 slot figure is restated as a slot size taken from tools/mech_gen.py, and RUL-EEG-021 is recorded as a document identifier.

Also within Rev B and without a further revision letter (2026-09-02): the EEG-CAR-01 row in section 2.4 is restated against the re-routed board. kicad/EEG-CAR-01_RevB_DRC_report.txt now records 145 of 145 nets fully connected and zero DRC violations, so the twenty-five open items and the two electrode-clearance vias at 0.328 mm are withdrawn from that row, and the fabrication data is released for review under RFQ-EEG-002A, with fabrication release awaiting that review. What has not changed: the routing has still not been read by a human layout engineer, 169 of its connections were relaxed to close, and no board has been fabricated.

Also within Rev B and without a further revision letter (2026-09-02), after the independent review of package v2.2: section 2.3 is re-registered against what mech/ actually holds. The two Rev B foam files this register named are withdrawn and deleted; the seven CASE-00 Rev C layer files are shipped, and CASE-00-03 to CASE-00-07 are registered here for the first time. The register had been carrying two layers against a seven-layer part, and pointing a foam cutter at two filenames that no longer exist. OA-8 is closed by the Rev C bay, and the honest part of it survives in section 2.3: the seven files are drawn and not released for cutting.

Also within Rev B and without a further revision letter (2026-09-02), after the design and firmware changes of that day: the EEG-CAR-01 row in section 2.4 no longer says that 47 kΩ is fitted and S-02 is not met – ECO-EEG-024 is applied, R1-R16 are 68 kΩ and S-02 is met at 36.8 µA on the calculation, with the safety sign-off still owed – and the FW-EEG-001 and FIX-01 rows in section 2.5 no longer say the firmware has never been compiled or that the contact-light phase driver does not exist. The firmware is built and the driver is written. Neither has run on hardware, no unit exists, and T11 has not been run.

A note on DSN-EEG-002 Rev E, which this register cites throughout. It has not been re-issued since package v2.1 and the shipped file is byte-identical, so its sections 7, 10 and 11 are cited here for geometry, materials and fitting only, and are superseded on three points: section 10’s HM-07 / HM-08 part numbering is superseded by sections 3.1 and 3.2 of this register (HM-08 is the battery hatch, HM-10 the keyed cell carrier, HM-07A/B/C the boom arm), and section 7’s “a charged spare travels in the case” is superseded by REG-EEG-012 Rev B section 3.1 and RISK-EEG-011 Rev B section 6.1, which record zero spare cells in circulation. Its section 11 travel-case figure, FIG-19 in the map of section 3.3 below, draws the two-layer foam and is superseded by the CASE-00 Rev C schedule of PKG-EEG-015 section 2.2 and by section 2.3 above. ECO-EEG-016 section 1.1 records the file as “released, not reissued in this round”; its re-issue is an open document action, not a decision still to be taken.

Also within Rev B and without a further revision letter (2026-09-02), after the completeness audit of package v2.3: twelve printed parts are re-registered from “to be created” to “exists”. HM-02B, HM-02C, HM-03A, HM-05B, HM-10, HM-11A, HM-11B, HM-11C, POD-P1-04, WH-ADP-02, WH-ADP-03 and WH-ADP-04 all have STL, STEP, a MECH-EEG-020 sheet and a mech/MANIFEST.json entry, and all three WH-KEY-01 forms do too; the register was telling a shop that parts sitting in mech/stl/ did not exist. Their model figures are read from the released meshes, the MECH-EEG-020 sheet numbers throughout §2 are corrected against mech/drawings/MECH-EEG-020_sheet_index.csv – the set is now 25 sheets, not 10 – and AVL-EEG-017 K24 names them so a print bureau can quote them. WH-BUS-01’s entry is corrected on both counts WH-EEG-008 open item 15 raised: it is a two-layer board, and its Gerber, drill, netlist and README set exists in kicad/wh-bus-01/. POD-P1-01’s volume is restated at 144.42 cm³ from the released mesh. Two new identifiers, HM-04A and HM-05C, are registered for the halves of the HM-04 electrical termination that WH-EEG-008 §3.1.1 proposes, and both are marked PROPOSED rather than allocated to a released part – OA-14, OA-15 and OA-16. The seven printed fixture solids released in fixtures/ are registered in §2.4 for the first time, named by their TST-EEG-004 §6.1 sub-assembly letter and their filename, because this register allocates none of that letter set itself – OA-17.

Also within Rev B and without a further revision letter (2026-09-02), after the design changes of 2 September 2026. Two released helmet parts were re-cut, a bought-in class of connector arrives in the register for the first time, and one harness number is reserved. HM-04 and HM-05B now assemble. The pair as released did not: the HM-05B lug stood at an outer radius of 5.40 mm against a 5.30 mm slot – 0.10 mm of radial interference and zero tangential clearance – and hm04() cut two straight axial slots with no circumferential run behind them, so the carrier could not enter and, if it had, could not turn. The lug is corrected to 5.20 mm, which is what hm05b()’s own docstring has always said, and raised to z 1.20–3.30; the entry slots are 1.70 mm wide at an outer radius of 5.55 mm and 3.60 mm deep; and HM-04 gains a 100° circumferential run at z 1.10–3.80 with 1.10 mm of retaining lip below it. tools/simulate_production.py measures the two solids at four rotations and three axial positions on every run and reports 0.000 mm³ through the quarter turn, 0.000 mm³ through the carrier’s 0.40 mm of spring travel and 1.557 mm³ of lip engagement when the seated carrier is pulled down. HM-04’s contact-light window is now two pockets with 1.60 mm of printed PA12 between them, an outboard LED seat and an inboard conductor run, where it was one box straight through the body – the arrangement RISK-EEG-011 SF-9 describes. HM-04’s spring seat is 6.60 mm deep, not 4.50, which takes the free height above the HM-05B spigot from 1.40 mm to 3.50 mm. The model figures of both parts move with all of this and are restated in §2.1 from the released meshes; both parts are owed a revision letter under rule 5 of §1.3, and the deepened seat is in tools/mech_gen.py and not yet in a released mesh – OA-18. Separately, WH-10 is reserved for the Fpz bias lead, and the 1.5 mm touch-proof DIN 42802-1 sockets for the two ear references and for the bias lead are registered in §2.4 as bought-in parts that take no identifier under rule 4 – OA-16, extended, and OA-19. Nothing here has been printed, and every one of these changes is a change to a source file and a mesh, not to a part.

Nothing in this package has been manufactured or measured, and no safety engineer has reviewed this design. Every dimension, volume and mass in this register is calculated from a released model file. No part has been printed, no board has been fabricated, and the first thing Phase 1 does is find out which of these figures are wrong.

## Why this document exists

Package v1 used the code HM-xx for two different things at once: as figure labels in DSN-EEG-002 Rev E and as part numbers in the same document’s section 10. Only HM-01 happened to mean the same thing in both. The consequence was not cosmetic. HM-07 named the boom microphone arm in DSN-EEG-002 section 10 and the battery hatch in DSN-EEG-003 section 4, in mech/HM-07_battery_hatch.stl, in mech/MANIFEST.json, in kit BOM item 17 and in the RFQ Rev C scope line – so a contract manufacturer printing “HM-07” produced a gooseneck arm or a quarter-turn hatch depending on which document was open, and whichever one was printed, the other part was silently dropped from the kit. DSN-EEG-002 section 10 also requires part IDs to be engraved into the model, so the wrong identifier would have been moulded into the part. This register fixes one identifier for each part in the package, states which file defines it and which document specifies it, and is cited by every other document in package_v2.3 (DSN-EEG-003 Rev D Annex A lists it sixth in the precedence order). It closes contradictions XD-01, XD-02 and XD-03 and gaps mech-hm07-part-number-conflict and mech-missing-part-files.

Rev B exists because the geometry moved underneath the register. Two findings came out of actually laying the carrier out instead of asserting that it would lay out, and both propagate into every printed part this document names.

The carrier grew from 130 x 124 mm to 150.0 x 130.0 mm. Thirty connectors, 211 parts and 156 nets would not close at the smaller size. At Phase 1 and Phase 2 quantities the extra 33.8 cm2 of bare board costs a few euro per unit against a real risk of an unroutable design, so the board grew.

The carrier went from two layers to four. Package v1’s architecture argument was that a two-layer carrier is cheap and easy to route. Doing the layout showed that it is not: on two layers the bottom side has to be both the reference plane and the second routing surface, and it cannot be both. Four layers – L1 signal, L2 reference plane, L3 reference plane, L4 signal – give two full routing surfaces and a continuous reference under every analogue trace, which is what DSN-EEG-002 section 13’s “layout rules that are requirements, not preferences” require, and what the zoning, star-point and isolation rules of DSN-EEG-003 section 3.3 require, and which a swiss-cheesed two-layer pour cannot deliver. The two citations are not interchangeable: DSN-EEG-002 section 13 carries the layout rules that are requirements, and DSN-EEG-003 has sections 1 to 11 plus annexes and no section 13, so a reference to “DSN-EEG-003 section 13” is stale and is corrected to one of these two. At 2 units the four-layer board is about EUR 35 more in total; at 50 units it is about EUR 3 per board.

The enclosure and the module plate grew with the board, and MP-01, POD-P1-01 and POD-P1-02 are therefore at new revisions in this issue. The change is recorded against EEG-CAR-01 in section 2.4 and in the migration table of section 3.2.

## 1. Naming rules

### 1.1 Four namespaces, never mixed

Namespace | Form | Owner | Example
Part identifiers | <PREFIX>-nn, optional letter suffix for a member of an assembly | this document | HM-08, HM-02A
Document identifiers | <TYPE>-EEG-nnn Rev X | ECO-EEG-016 | DSN-EEG-002 Rev E
Requirement identifiers | E-nn, F-nn, A-nn, M-nn, S-nn, O-nn | RFQ-EEG-001 Rev E | M-05, S-09
Reference designators | R, C, D, J, L, F, U, SW, TP, FID, MH + number | tools/design.py | J14, R90, TP13, FID2, MH1
Figure labels | FIG-nn | the document that carries the figure | FIG-18

TP and FID are in the designator list because Rev B of the carrier has eighteen test points (TP1 to TP18, RFQ E-28) and three global fiducials (FID1 to FID3, ECO-EEG-020) that Rev A of this register did not list. They are reference designators owned by design.py, not part identifiers, and no fiducial or test point is ever given an HM, POD or MP number.

A figure label must never begin with a part prefix. This is the rule that XD-02 exists to create: in package v1 the caption “HM-07 – the frame unmounted” and the part “HM-07 boom microphone arm” sat eleven lines apart in the same section. Figures are numbered FIG-01 upward in document order within each document, and are cited from outside as DSN-EEG-002 FIG-18. Section 3.3 gives the full v1-to-v2 figure map for DSN-EEG-002.

The document namespace is ECO-EEG-016’s, and it currently has the same fault this register was written to fix for parts. The package cites as governing or required about nineteen document numbers that are not on the ECO-EEG-016 section 1 register, and six of them collide numerically with registered documents – REL-EEG-009 against JIG-EEG-009, PROV-EEG-007 against ASM-EEG-007, KEY-EEG-008 against WH-EEG-008, SD-EEG-013 against SVC-EEG-013, OTA-EEG-014 against IFU-EEG-014 and CAL-EEG-012 against REG-EEG-012. That is not this register’s namespace to repair and it is recorded here only as OA-11, against ECO-EEG-016. Two of the numbers that were unregistered when Rev A was written are now on that register: RUL-EEG-021, the rulings register, and SIM-EEG-018, the production simulation report, both at Rev A in docs/.

RUL-EEG-021 is a document identifier and never a part identifier. It is a controlled document on the ECO-EEG-016 section 1 register, it takes the <TYPE>-EEG-nnn Rev X form of row 2 of the table above, and it is cited as RUL-EEG-021 with a section letter – for example RUL-EEG-021 section A for the geometry rulings and section B for the instrument rulings. No RUL prefix exists in the part namespace of section 1.2, no RUL number is ever allocated to a printed, bought-in or fabricated item, and nothing in section 2 of this register carries one. SIM-EEG-018 is read the same way: a document number, and a record rather than a specification.

### 1.2 Prefixes and number ranges

Prefix | Covers | Range | Allocated | Reserved for
HM | Helmet: frame, pads, fixation, electrode assemblies, hatch, key, cell carrier, channel covers | HM-01 to HM-19 | HM-01 to HM-11 | HM-12 to HM-19, Phase 2
POD | Electronics enclosure and its fittings. Phase variant in the identifier: -P1 bench, -H2 in-helmet | POD-P1-01 to -19, POD-H2-01 to -19 | POD-P1-01 to -05 | Phase 2 occipital shell
CASE | Travel case, foam, packing printed matter | CASE-00 (foam family, historic), CASE-01 to CASE-09 | CASE-00-01 to -07, CASE-01 to -03 | CASE-04 to -09
MP | Module plate and its hardware | MP-01 to MP-09 | MP-01 | plate variants
WH | Cable and harness assemblies, and their named sub-assemblies | WH-01 to WH-19, plus WH-KEY-nn, WH-BUS-nn, WH-ADP-nn | WH-01 to WH-07, WH-09; WH-10 reserved and not issued (Fpz bias lead – §2.4, OA-19); WH-KEY-01, WH-BUS-01, WH-ADP-01/-01B/-02/-03/-04 | Phase 2 umbilicals
EEG-CAR | Carrier printed circuit board | EEG-CAR-01 to -09 | EEG-CAR-01 | EEG-CAR-02/-03, the Phase 2 split boards
FIX | Production test fixtures, and their own printed parts as FIX-nn-mm | FIX-01 to FIX-19 | FIX-01 to FIX-04 | further stations
FIT | Fit-test and process coupons | FIT-01 to FIT-09 | FIT-01 | collar and lug coupon
FW | Firmware images and host tools | FW-EEG-nnn | FW-EEG-001 | host tools

FIT is a ninth prefix, not in the original scheme. It is here because mech/stl/FIT-01_fit_test_coupon.stl was released before this register and tools/mech_gen.py governs the filename; inventing a tenth name for a file that already exists would recreate the fault this document is closing.

The three WH sub-forms are the one exception to the <PREFIX>-nn rule, and they are here for the same reason FIT is: WH-EEG-008 Rev B already uses WH-KEY-01, WH-BUS-01 and WH-ADP-01 to WH-ADP-04 in its wire lists, its build order and its test record, and renaming them into the plain WH-nn run would put a keying shroud and a cable in the same number series and invite exactly the confusion described above. The sub-form is read as “WH namespace, KEY / BUS / ADP family, member nn”. No WH-nn cable number is ever reused for a sub-assembly and no sub-assembly number is ever shortened to WH-nn.

WH-08 is withdrawn and its number is not reused. It named a captive 2 m host USB-C lead leaving the pod through a Lapp SKINTOP gland. The host connection is a socket, not a captive cable, so WH-08 and the gland are deleted from the Phase 1 build; see section 2.4 and WH-EEG-008 Rev B section 1.

### 1.3 Rules of use

1. One identifier, one part. If two things can be ordered, printed, inspected or scrapped separately, they are two parts and they get two identifiers.
2. The filename begins with the identifier. HM-08_battery_hatch.stl is HM-08. The two exceptions are the POD-P1 and CASE-00 families, whose filenames carry the family token and whose members are distinguished by the descriptive tail; the register table in section 2 gives the mapping explicitly for those four files.
3. A letter suffix means a member of a named assembly, not a revision. HM-02A is the brow pad; the revision of HM-02A is carried in its own column and is never written into the identifier.
4. Bought-in catalogue items get no identifier unless the programme modifies them or a printed interface part exists for them. An unmodified Nanuk case, an Ambu snap pad or a Panasonic cell is identified by its supplier part number and its AVL-EEG-017 line. The ratchet mechanism, the gooseneck and the sintered cup are modified or mated to printed parts, so they carry identifiers.
5. A revision letter belongs to the part, not to the package. Any change to a released file raises the letter. HM-04 and HM-08 are at Rev B because their models were rebuilt parametrically; MP-01, POD-P1-01 and POD-P1-02 are at Rev B because the carrier grew and they were resized to match. Neither is because the package revised.
6. Nothing in this register has been manufactured. Every dimension and volume quoted is calculated from the released mesh, not measured on a part.

## 2. The register

Bounding boxes and volumes are calculated from the released STL in package_v2.4/mech/stl/ (bounding box from the vertex extremes, volume by the divergence theorem over the closed mesh). They are model figures. No part has been printed, so no figure here has been verified against hardware.
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

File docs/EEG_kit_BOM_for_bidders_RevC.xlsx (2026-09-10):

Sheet: Kit BOM
Item | Group | Description | Reference part / module | Approved alternate | Qty per kit | Qty @2 | Qty @10 | Qty @25 | Qty @50 | Substitutable | Notes | Bidder unit price @2 | @10 | @25 | @50 | Bidder notes
1 | Modules | ADS1299 8-channel breakout with SPI header and on-board regulators; DAISY_IN and CLKOUT accessible | PIEEG-8 module | generic ADS1299 breakout meeting ICD-EEG-006 section 2.1 | 2 | 4 | 20 | 50 | 100 | No (module class fixed) | Fitted twice per unit. Interface, not brand, is what is specified
2 | Modules | ESP32-S3 development board, 16 MB flash, 8 MB octal PSRAM | Espressif ESP32-S3-DevKitC-1-N16R8 | none | 1 | 2 | 10 | 25 | 50 | No | Inserted directly into J6/J7 on 22.86 mm row spacing. GPIO35, 36, 37 and 45 are not connected on the carrier
3 | Modules | Audio codec module with headphone amplifier, I2S | ES8388 breakout | WM8960 module (firmware change) | 1 | 2 | 10 | 25 | 50 | Yes
4 | Modules | USB 2.0 full-speed isolator module, >= 2.5 kV RMS | ADuM4160 isolator module | none | 1 | 2 | 10 | 25 | 50 | No | OPEN, and NOT closed by the interim answer. The candidate module presents USB-B and E-24 asks for USB-C; the WH-09 panel pigtail is the interim answer and E-24 says of it, in terms, 'it is not a settled design'. WHAT IS MISSING is an ADuM4160-class isolator module with a USB-C host connector, qualified against E-24 and the DSN-EEG-003 section 3.3 isolation keep-out. Until one exists the non-conformance is live and is carried, not resolved. Bidders who know of such a module should say so
5 | Modules | Secure element breakout, I2C | Adafruit ATECC608 breakout (4314) | any ATECC608B breakout | 1 | 2 | 10 | 25 | 50 | No
6 | Modules | Li-ion charger with power path and CE pin | Adafruit bq24074 (4755) | MCP73871 module | 1 | 2 | 10 | 25 | 50 | Yes | Combined charger-plus-gauge assembly is the baseline
7 | Modules | Battery fuel gauge, I2C | Adafruit MAX17048 (5580) | BQ27441 module | 1 | 2 | 10 | 25 | 50 | Yes | May be combined with the charger on one board
8 | Modules | Buck-boost regulator module, VSYS to 5.00 V at 1 A | TPS63020 breakout | TPS63070 module | 1 | 2 | 10 | 25 | 50 | Yes | NEW IN v2. Package v1 had no source for the 3.3 V rail at all (ECO-EEG-002)
9 | Modules | microSD breakout, SDMMC | generic microSD SDMMC breakout | none | 1 | 2 | 10 | 25 | 50 | Yes | One-bit SDMMC. 70 kB/s needed, about 2 MB/s available
10 | Modules | Electret microphone preamplifier module, fixed gain | MAX4466 class (Adafruit 1063) | none -- specified by interface, ICD-EEG-006 section 2.9 | 1 | 2 | 10 | 25 | 50 | Yes | OPEN, but narrower than it was. The AGC CONFLICT IS RESOLVED: the MAX9814 of package v1 is an AGC part, is NOT APPROVED, and is superseded here -- E-14 requires AGC off, and the fixed-gain MAX4466 class named here is E-14's own preferred route. What is still open is the SELECTION, not the conflict -- E-14 reads 'which preamplifier is not settled' and specifies the module BY INTERFACE in ICD-EEG-006 section 2.9 until one is bought and measured. Quote against the interface. Mounts on MP-01 at J21; the boom carries the bare capsule
11 | Modules | Room microphone module with hardware mute | to be selected | none | 1 | 2 | 10 | 25 | 50 | Yes | OPEN, and the only row in this BOM with NO PART AT ALL. E-15 requires the audio path to be hardware-gatable on MIC_MUTE (GPIO21); a catalogue search found no breakout with a mute pin -- the common electret and MEMS boards (SparkFun, Pololu, Adafruit 1063, INMP441) bring out audio and power only. The fallback is a capsule plus a TS5A3159 analogue switch on a programme-designed adapter, which is a NEW DRAWING and has not been drawn. Thirteen module assemblies per unit and this is the unspecified one. Bidders: quote the other twelve and say whether you would build the adapter to a drawing when one exists
12 | Modules | 8-bit shift register module | 74HC595 breakout | none | 1 | 2 | 10 | 25 | 50 | Yes | Q0..Q7 must be brought out. In v1 they were not, and the contact lights had no driver at all (ECO-EEG-001)
13 | Modules | Protected 18650 Li-ion cell >= 3000 mAh, UN 38.3 | Panasonic NCR18650B protected | Samsung 35E in a protection holder | 1 | 2 | 10 | 25 | 50 | Yes | UN 38.3 test summary required with the first delivery
14 | Modules | microSD card 32 GB high endurance | SanDisk Industrial | Kingston SDCIT2 | 1 | 2 | 10 | 25 | 50 | Yes
15 | Carrier | EEG-CAR-01 Rev B carrier PCB, FOUR layers, 150.0 x 130.0 mm, ENIG | fabricated from the released Gerber set | none | 1 | 2 | 10 | 25 | 50 | n/a | v1 specified two layers and 130 x 124 mm; see DSN-EEG-003 Rev D section 3
16 | Carrier | EEG-CAR-01 assembly per the carrier sub-BOM sheet | see sheet 'Carrier sub-BOM' | per sub-BOM alternates | 1 | 2 | 10 | 25 | 50 | Per sub-BOM
17 | Carrier | Ribbon-jumper set, keyed, per ICD-EEG-006 section 3 | 2.54 mm IDC ribbon, made up | none | 1 | 2 | 10 | 25 | 50 | Yes | Maximum 60 mm on the analogue jumper
18 | Printed | HM-01 helmet frame monocoque, PA12 MJF | MJF PA12, dyed graphite | SLS PA12 | 1 | 2 | 10 | 25 | 50 | Process only | About 240 g
19 | Printed | HM-04 electrode assembly body | MJF PA12 | SLS PA12 | 10 | 20 | 100 | 250 | 500 | Process only | Eight fitted, two spare
20 | Printed | HM-08 battery hatch (called HM-07 in v1 -- see PARTS-EEG-019) | MJF PA12 | SLS PA12 | 1 | 2 | 10 | 25 | 50 | Process only
21 | Printed | HM-07 boom microphone arm | MJF PA12 + gooseneck | none | 1 | 2 | 10 | 25 | 50 | Process only
22 | Printed | MP-01 module mounting plate | MJF PA12 | none | 1 | 2 | 10 | 25 | 50 | Process only | NEW IN v2. 146.0 x 126.0 x 3.0 mm
23 | Printed | POD-P1 enclosure base and lid -- Phase 1 only | MJF PA12 or FDM PETG | none | 1 | 2 | 10 | 25 | 50 | Process only | 163.0 x 143.0 x 58.0 mm external
24 | Printed | HM-02 TPU comfort pads x4 and chin-cup liner | TPU 85A | cast | 1 | 2 | 10 | 25 | 50 | Yes | Consumable, replaced every turnaround
25 | Printed | HM-09 service key | MJF PA12 | none | 0 | 0 | 0 | 0 | 0 | Process only | ONE PER OPERATOR, deliberately NOT in the participant's kit
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

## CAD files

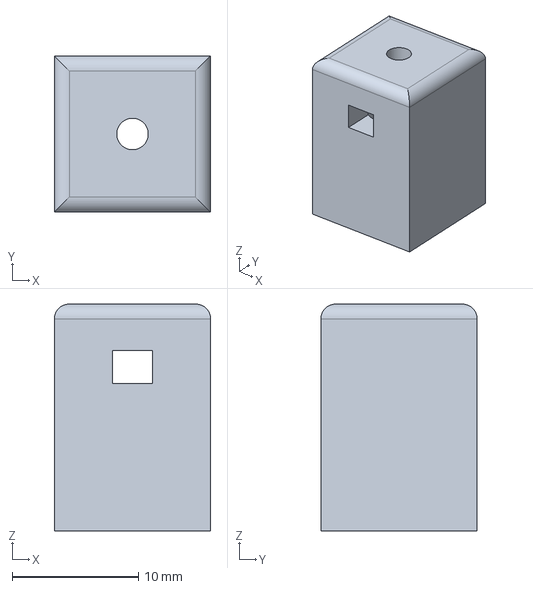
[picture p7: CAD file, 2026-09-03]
mech/step/HM-04_electrode_assembly_body.step
12.4 x 12.4 x 18.0 mm

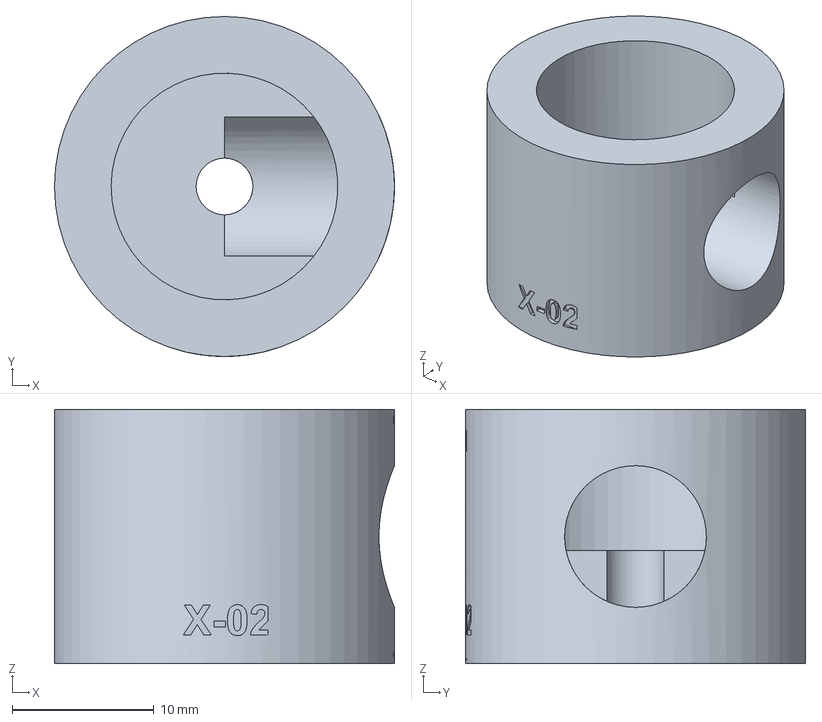
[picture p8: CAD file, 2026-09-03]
fixtures/step/FIX-02A_voice_coupler_body.step
24.0 x 24.0 x 17.9 mm

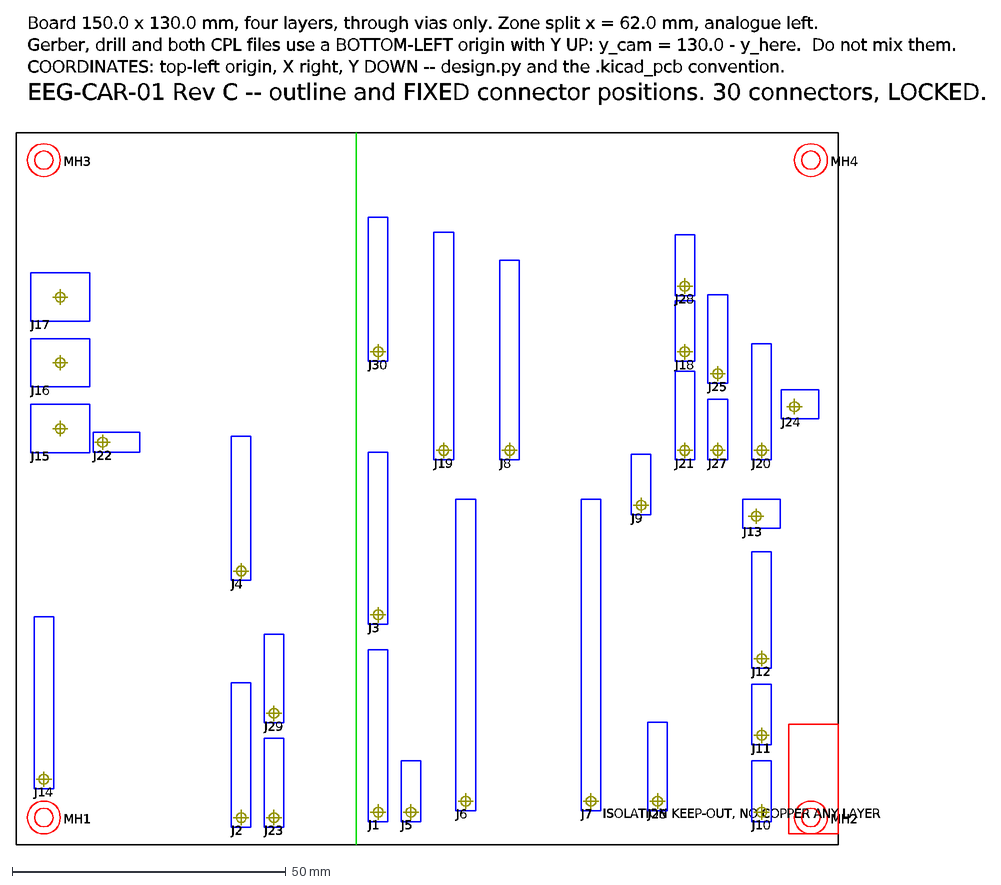
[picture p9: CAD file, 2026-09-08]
kicad/RevC_layout_inputs_kicad10/EEG-CAR-01_RevC_outline_and_fixed_connectors.dxf
MH1
MH2
MH3
MH4
ISOLATION KEEP-OUT, NO COPPER ANY LAYER
J1
J10
J11
J12
J13
J14
J15
J16
J17
J18
J19
J2
J20
J21
J22
J23
J24
J25
J26
J27
J28
J29
J3
J30
J4
J5
J6
J7
J8
J9
EEG-CAR-01 Rev C -- outline and FIXED connector positions. 30 connectors, LOCKED.
COORDINATES: top-left origin, X right, Y DOWN -- design.py and the .kicad_pcb convention.
Gerber, drill and both CPL files use a BOTTOM-LEFT origin with Y UP: y_cam = 130.0 - y_here. Do not mix them.
Board 150.0 x 130.0 mm, four layers, through vias only. Zone split x = 62.0 mm, analogue left.

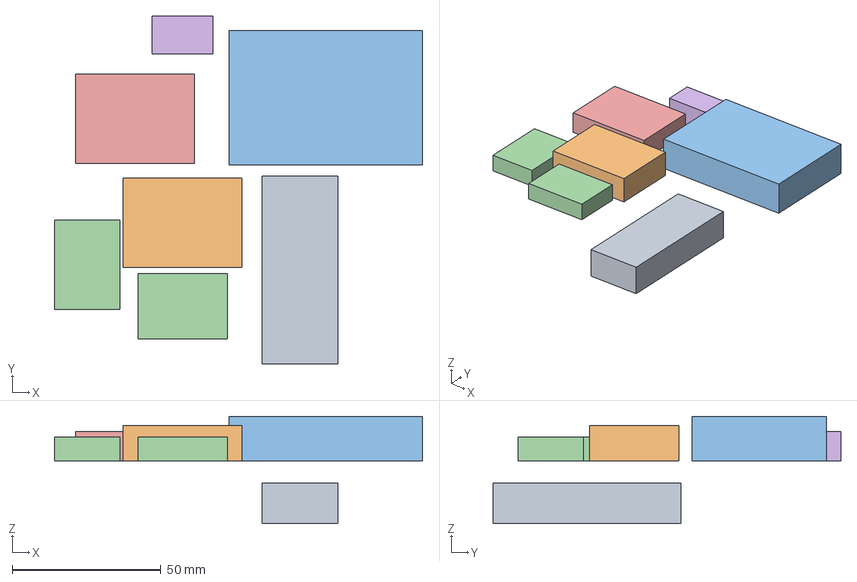
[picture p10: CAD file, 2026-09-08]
kicad/RevC_layout_inputs_kicad10/step/EEG-CAR-01_RevC_module_envelopes.step
123.5 x 116.7 x 36.0 mm

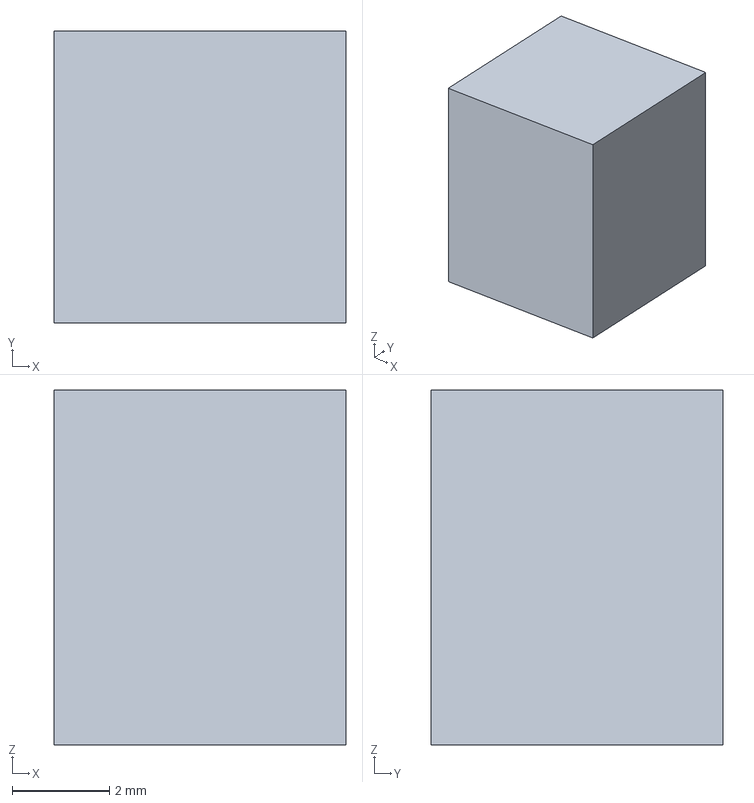
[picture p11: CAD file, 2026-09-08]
kicad/RevC_layout_inputs_kicad10/step/footprints/SW_PUSH_6mm_H7.3mm.step
6.00 x 6.00 x 7.30 mm

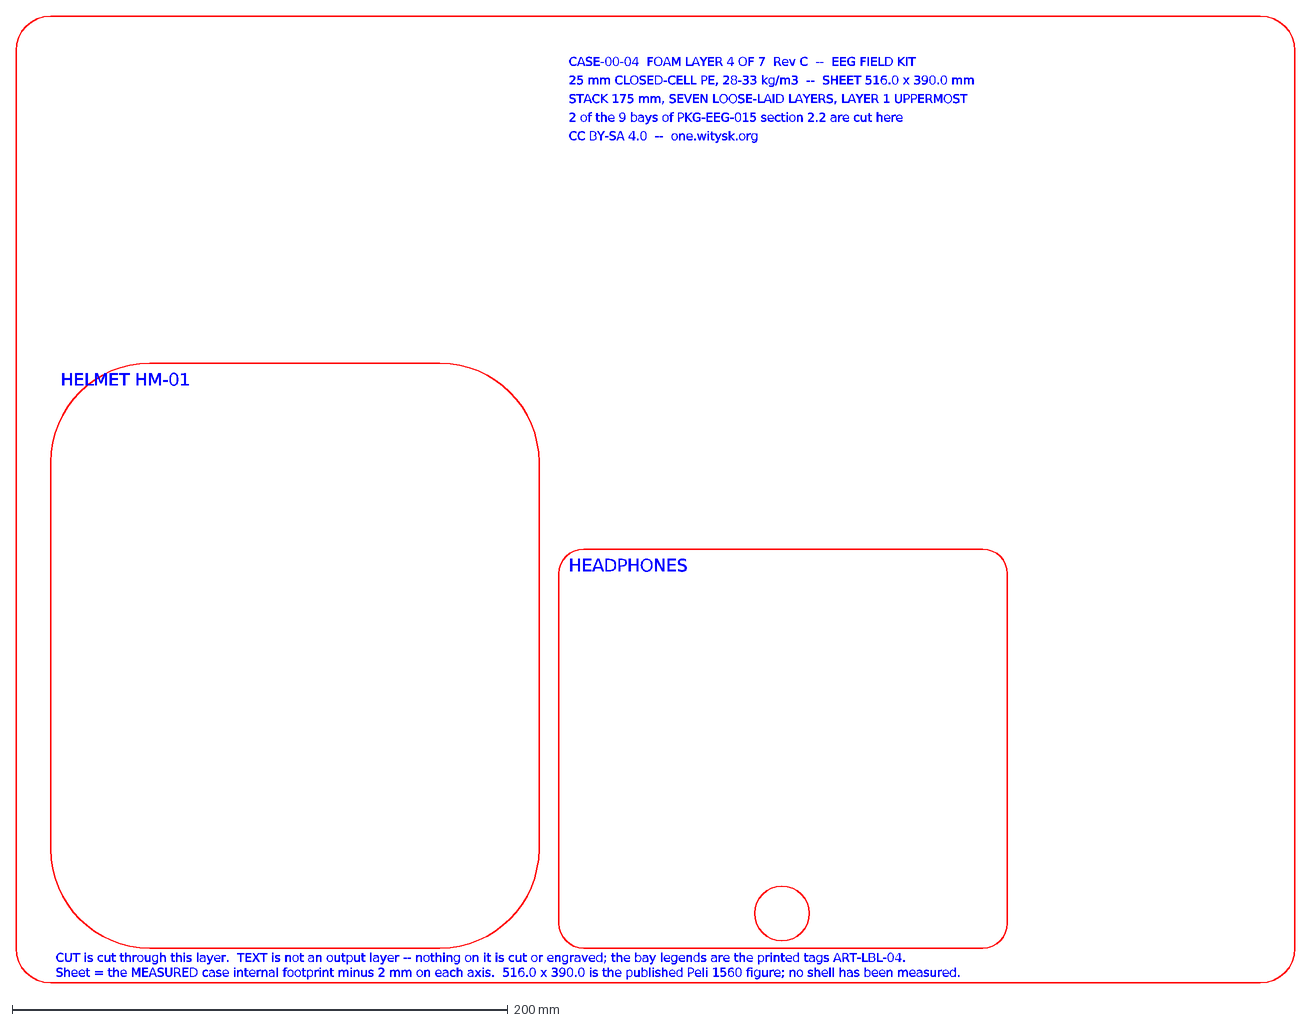
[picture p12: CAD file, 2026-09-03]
mech/CASE-00_foam_layer_4.dxf
HELMET HM-01
HEADPHONES
CASE-00-04 FOAM LAYER 4 OF 7 Rev C -- EEG FIELD KIT
25 mm CLOSED-CELL PE, 28-33 kg/m3 -- SHEET 516.0 x 390.0 mm
STACK 175 mm, SEVEN LOOSE-LAID LAYERS, LAYER 1 UPPERMOST
2 of the 9 bays of PKG-EEG-015 section 2.2 are cut here
CC BY-SA 4.0 -- one.witysk.org
CUT is cut through this layer. TEXT is not an output layer -- nothing on it is cut or engraved; the bay legends are the printed tags ART-LBL-04.
Sheet = the MEASURED case internal footprint minus 2 mm on each axis. 516.0 x 390.0 is the published Peli 1560 figure; no shell has been measured.

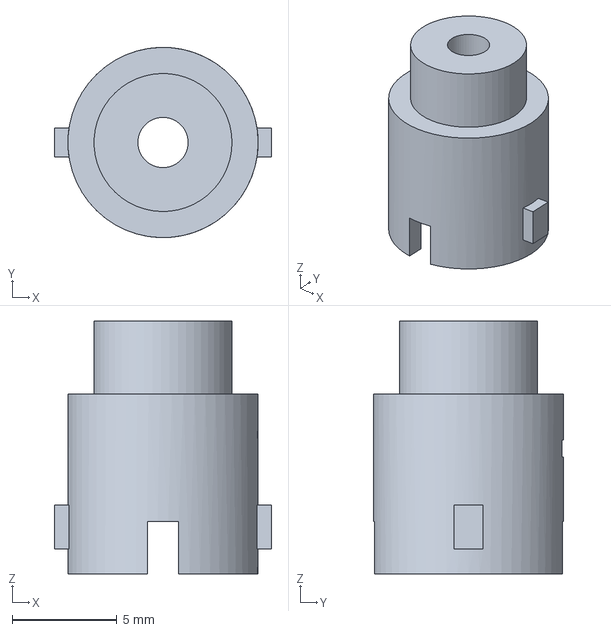
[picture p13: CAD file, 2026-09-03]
mech/step/HM-05B_cup_bayonet_carrier.step
10.4 x 9.10 x 12.1 mm

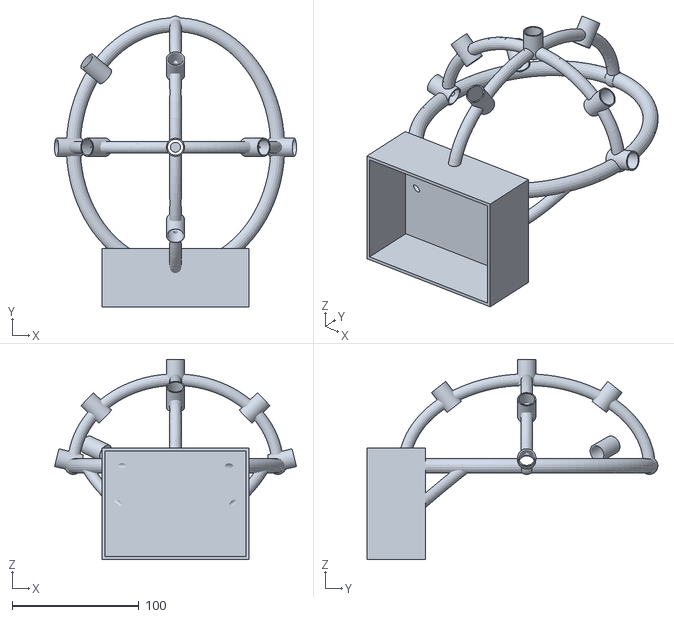
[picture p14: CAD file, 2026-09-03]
mech/stl/HM-01_frame_monocoque.stl
191.1 x 229.6 x 158.0

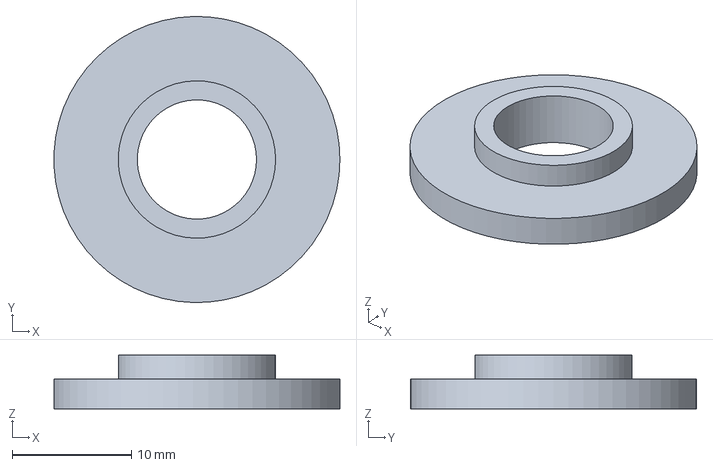
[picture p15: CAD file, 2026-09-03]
fixtures/step/FIX-02A_sealing_lip.step
24.0 x 24.0 x 4.50 mm

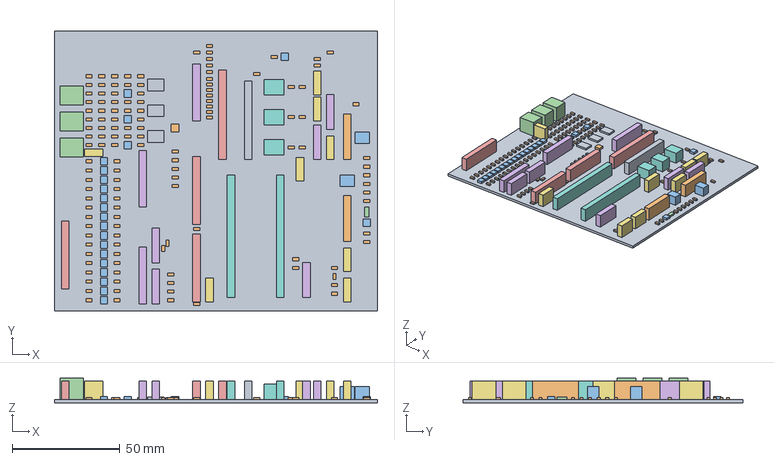
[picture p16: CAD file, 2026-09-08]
kicad/RevC_layout_inputs_kicad10/step/EEG-CAR-01_RevC_carrier_envelopes.step
150.0 x 130.0 x 11.6 mm

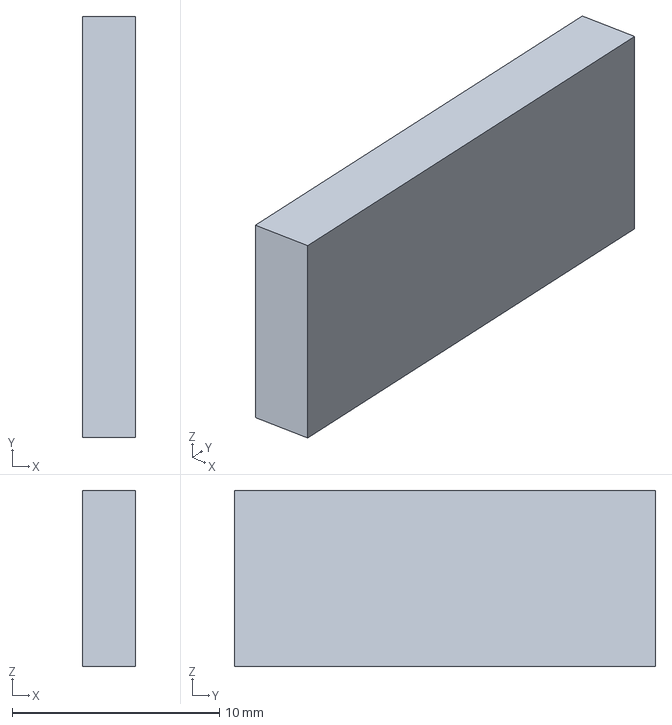
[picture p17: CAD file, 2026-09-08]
kicad/RevC_layout_inputs_kicad10/step/footprints/PinSocket_1x08_P2.54mm_Vertical.step
2.54 x 20.3 x 8.50 mm

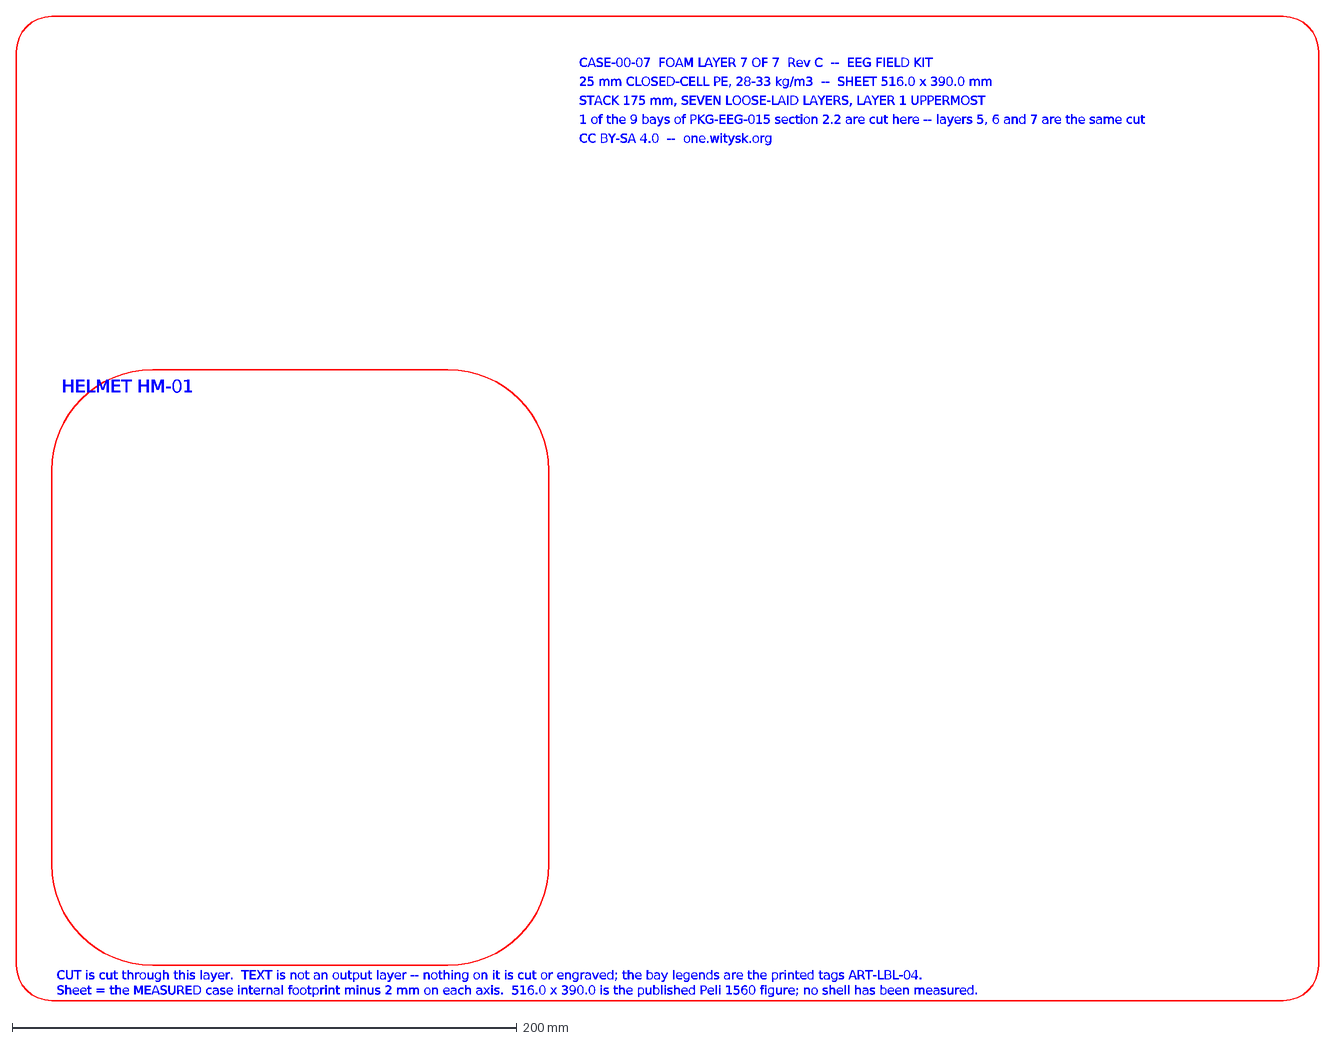
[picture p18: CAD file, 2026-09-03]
mech/CASE-00_foam_layer_7.dxf
HELMET HM-01
CASE-00-07 FOAM LAYER 7 OF 7 Rev C -- EEG FIELD KIT
25 mm CLOSED-CELL PE, 28-33 kg/m3 -- SHEET 516.0 x 390.0 mm
STACK 175 mm, SEVEN LOOSE-LAID LAYERS, LAYER 1 UPPERMOST
1 of the 9 bays of PKG-EEG-015 section 2.2 are cut here -- layers 5, 6 and 7 are the same cut
CC BY-SA 4.0 -- one.witysk.org
CUT is cut through this layer. TEXT is not an output layer -- nothing on it is cut or engraved; the bay legends are the printed tags ART-LBL-04.
Sheet = the MEASURED case internal footprint minus 2 mm on each axis. 516.0 x 390.0 is the published Peli 1560 figure; no shell has been measured.

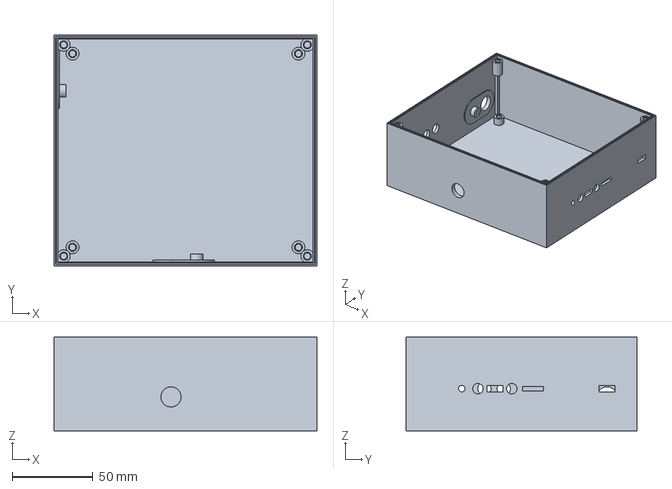
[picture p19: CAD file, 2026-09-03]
mech/step/POD-P1_prototype_enclosure_base.step
163.0 x 143.0 x 58.0 mm

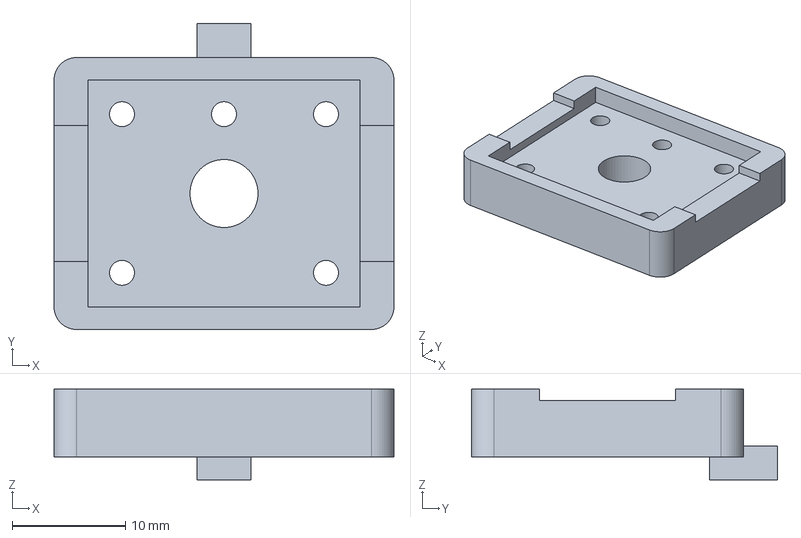
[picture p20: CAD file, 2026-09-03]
fixtures/step/FIX-01E_sensor_carrier.step
30.0 x 27.0 x 8.00 mm

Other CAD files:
kicad/RevC_layout_inputs_kicad10/step/footprints/PinSocket_1x02_P2.54mm_Vertical.step
kicad/RevC_layout_inputs_kicad10/step/MP-01_RevC_plate_and_standoffs.step
mech/CASE-00_foam_layer_2.dxf
mech/step/WH-ADP-04_host_usb_c_plate.step
fixtures/step/FIX-01E_colorimeter_manifold.step
fixtures/step/FIX-02B_room_coupler_body.step
fixtures/step/FIX-02B_sealing_lip.step
fixtures/step/FIX-03A_carrier_nest.step
fixtures/stl/FIX-01E_colorimeter_manifold.stl
fixtures/stl/FIX-01E_sensor_carrier.stl
fixtures/stl/FIX-02A_sealing_lip.stl
fixtures/stl/FIX-02A_voice_coupler_body.stl
fixtures/stl/FIX-02B_room_coupler_body.stl
fixtures/stl/FIX-02B_sealing_lip.stl
fixtures/stl/FIX-03A_carrier_nest.stl
kicad/RevC_layout_inputs_kicad10/step/footprints/C_0603_1608Metric.step
kicad/RevC_layout_inputs_kicad10/step/footprints/DIN42802_1p5mm_Socket.step
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

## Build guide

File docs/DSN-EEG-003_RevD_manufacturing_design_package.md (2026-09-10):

# EEG Field Kit -- Manufacturing Design Package

**Document:** DSN-EEG-003 **Revision:** D **Date:** 1 September 2026
**Issued by:** TI One Voice research programme (one.witysk.org), Brussels, Belgium
**Licence:** hardware and documents CC BY-SA 4.0; firmware MIT
**Supersedes:** Rev C of this document in its entirety, which superseded Rev B
**Revision note (Rev C):** the carrier is now 150.0 × 130.0 mm and four layers rather than
130 × 124 mm and two, the enclosure and module plate grew to match, the ECO register runs to
ECO-EEG-027, and every finding of the 1 September 2026 cross-document audit is closed here or
named as open. The findings of the second cross-document audit of 1 September 2026 are also
closed in this issue: section 3.4 now carries the routing result and the release state
transcribed from the DRC report, section 6 cites TST-EEG-004 Rev C by its own section
numbers, and the rulings register RUL-EEG-021 and the production simulation SIM-EEG-018 are
in Annex A. These are corrections within the Rev C release and the revision letter is not
advanced for them.

**Correction within Rev C, 2 September 2026.** The carrier now routes to completion: the DRC
reports **zero violations, all 145 nets one connected copper island, and both inner planes
continuous under the analogue zone** -- the three conditions of the ECO-EEG-016 section 3 gate.
Section 3.4 carries that result. **It is superseded as a release state.** A layout engineer
read the Rev B board between 3 and 5 September 2026, declined the review and advised a
redesign; **Rev B is withdrawn from fabrication and Rev C is unrouted, with its placement and
routing bought** (ECO-EEG-016 section 2, ECO-EEG-030). Six of his seven findings were rules
this DRC did not have, and the same geometry regraded under them shows 1 311 occurrences. ECO-EEG-016 section 2B records how the board was closed. This too is a
correction within the Rev C release and the revision letter is not advanced for it.

**Second correction within Rev C, 2 September 2026, after the independent review of package
v2.2.** Section 4's mechanical file table listed two CASE-00 foam DXFs that no longer exist:
`mech/` holds the seven **Rev C** layer files and the Rev B pair is deleted. The table is
rewritten against the shipped files, and the true part of the old entry is kept -- the seven are
drawn and **not released for cutting**. Annex A's SIM-EEG-018 figures, which stood at two
different totals in this document, are now quoted from the run of `tools/simulate_production.py`
of 2 September 2026. Annex A also marks which sections of DSN-EEG-002 Rev E are superseded,
because that document has not been re-issued and is cited here as a live source.

**Third correction within Rev C, 2 September 2026, after the design and firmware changes made
that day.** Four things this document carried as open are now closed in the design, and they
are corrected in place, with their date, rather than deleted. **S-02 is met** at 36.8 µA:
ECO-EEG-024 is applied and R1-R16 are 68 kΩ, not 47 kΩ. **E-11 is met in both halves**:
the Sallen-Key low-pass moved from X7R to C0G -- 10 nF and 22 nF with 215 kΩ, f0 49.9 Hz.
**E-27 is met**: the bicolour contact-light phase driver is written. And **the firmware is
built**, against a real ESP-IDF v5.2.5, and has booted once under QEMU. The bias-lead topology
was fixed in the same pass -- D11 and C11 now sit on BIASOUT behind the series resistor like
the other fifteen channels -- and the board came out of that repair at **145 of 145 nets, zero
violations, 3 745 track segments and 552 vias**. None of this is hardware: no board has been
fabricated, no firmware has run on silicon, and no safety reviewer has signed anything.
`KNOWN_ISSUES.txt` section 0i is the record of the change. This too is a correction within the
Rev C release and the revision letter is not advanced for it.

**This is the governing document of package v2.** Where any other document in the package
disagrees with it, this one governs -- with one exception: where a number appears both here
and in `tools/design.py`, `design.py` governs, because every fabrication file is generated
from it.

---

## Why this revision exists

Rev A.2 said, honestly, that a manufacturer could quote from the package but could not build
from it, because the carrier board was placed and netlisted but unrouted and the firmware had
never been compiled. It also said that the files had been attacked for consistency. They had
not been attacked hard enough.

Package v2 was produced by generating the whole carrier from a single machine-readable design
description and then checking it -- netlist connectivity, geometric clearances, zone rules,
star-point uniqueness -- against that description rather than against prose. Doing so found
fourteen defects in Rev A that the prose review had missed, four of which made the board
impossible to build at all:

* the eight contact-light lines existed on the harness connector with **nothing driving them**;
* there was **no source for the 3.3 V rail** -- the charger's system output, the DevKit's 5 V
  pin and both ADS1299 module supplies were all unconnected nets, so the board could not
  have powered up;
* the second amplifier of each envelope detector had **its inverting input unconnected**, so
  the 50 Hz filter was not in circuit;
* the shift-register lines were assigned to **GPIO35, 36 and 37, which carry the octal PSRAM**
  on the ESP32-S3-DevKitC-1-N16R8, so the firmware pin map could not have worked.

There were also no mounting holes, although the specification sheet promised four; the
DevKit header spacing was 22.0 mm where the real part is 22.86 mm; and the six non-plated
retention holes of the touch-proof EMG sockets were declared on the copper and mask layers,
which would have plated them and tied those sockets to the analogue reference pour.

**Rev C exists because doing the layout, rather than asserting that the layout would be
easy, changed the board twice.** Package v1 and Rev B both stated that a two-layer carrier of
130 × 124 mm was enough. It is not, and the two findings are engineering results rather than
preferences:

* **The board grew to 150.0 × 130.0 mm.** Thirty connectors, 211 reference designators and
  156 nets would not close at the smaller outline. The extra 33.8 cm² of bare board costs a few
  euro per unit at these quantities, against a real risk of an unroutable design.
* **The board went to four layers: L1 signal, L2 reference plane, L3 reference plane, L4
  signal.** On two layers the bottom side has to be both the reference plane and the second
  routing surface, and it cannot be both. Four layers give two full routing surfaces and a
  continuous reference under every analogue trace, which is exactly what the "layout rules
  that are requirements, not preferences" of **DSN-EEG-002 section 13** ask for, and what the
  zoning, star-point and isolation rules of **section 3.3 below** ask for, and which a
  swiss-cheesed two-layer pour cannot deliver. At 2 units the extra cost
  is about €35 in total; at 50 units it is about €3 per board. That is the right trade for a
  sixteen-channel EEG front end, and it is the single most important thing package v2 learned
  by doing the work instead of asserting it.

A cross-document audit of the whole package on 1 September 2026 then found sixty places where
seventeen documents written from one fact base disagreed with each other, with the fact base,
or with `design.py`. Every one has been ruled on. The rulings that change the design are
ECO-EEG-019 to ECO-EEG-027, indexed in section 9 and written out in ECO-EEG-016 section 2.

What has *not* changed is the honest line at the end of Rev A.2, and it is repeated in
section 11: no safety engineer has reviewed this design, the firmware has never run on
hardware, and nothing here has been manufactured or measured.

---

## 1. What the manufacturers said, and what package v2 answers

Nine manufacturers answered RFQ-EEG-001. Read together, their replies define the production
package a manufacturer needs. Rev A.2 delivered part of it. This is the complete list and
where each item now is.

| What a manufacturer asked for | Where it is in package v2 |
|---|---|
| Routed Gerbers | `kicad/gerber/` -- Gerber X2, one file per copper, mask, legend and paste layer plus the board profile, zipped and checksummed. Four copper layers, not two |
| Drill data | `kicad/gerber/EEG-CAR-01-PTH.drl` and `-NPTH.drl`, Excellon 2, metric, split plated / non-plated. Through vias only |
| Netlist for bare-board test | `kicad/gerber/EEG-CAR-01-IPC-D-356A.ipc` |
| BOM with part numbers | `kicad/EEG-CAR-01_RevB_BOM.csv` and AVL-EEG-017 |
| Pick-and-place | `kicad/EEG-CAR-01_RevB_CPL_SMT_top.csv` (SMT) and `_CPL_THT_top.csv` (through-hole) |
| Fabrication drawing | `kicad/EEG-CAR-01_RevB_fabrication_drawing.pdf` -- outline, drill schedule, stack-up, notes |
| Assembly drawing | `kicad/EEG-CAR-01_RevB_assembly_drawing.pdf` -- designators, pin 1, DNP list, process notes |
| Schematic | `schematic/SCH-EEG-005_RevB_schematic_set.pdf` -- eight sheets. Rev A had none at all |
| Firmware | `firmware/` -- source, build system, configuration, provisioning script, host tool |
| Validated production-test specification | TST-EEG-004 Rev C, standalone, with fixtures in JIG-EEG-009 Rev C |
| Mechanical files | `mech/` -- STL, STEP, 2D drawings in MECH-EEG-020, DXF for all seven CASE-00 Rev C foam layers |
| Everything else a line needs | ICD-EEG-006, ASM-EEG-007, WH-EEG-008, QP-EEG-010, PKG-EEG-015 |

The carrier board file name keeps its `RevB` stem because `EEG-CAR-01` is still board revision
B: Rev C of this document changes the outline and the layer count of that board, and the
fabrication set is regenerated in one pass by `tools/emit_all.py` from `tools/design.py`. A
manufacturer holding an older Gerber set with a 130 × 124 mm profile or a two-layer stack-up
has a superseded set and must ask for the current one.

Regulus's correction to our contact list is carried forward: that company is ISO 9001, not
ISO 13485. The RFQ requests no certification, so this is informational, but the contact
workbook has been corrected.

---

## 2. Architecture: modules on a carrier

Unchanged in principle from Rev A.2, and the reasoning stands: buy every block that is hard
to get right and design only the board that connects them. What has changed is that the
connection is now specified properly.

**Twelve module types, thirteen module assemblies per unit** -- the ADS1299 breakout is
fitted twice. Twelve of the thirteen mount on the MP-01 module plate; the
ESP32-S3-DevKitC-1-N16R8 is inserted directly into J6 and J7. The carrier carries **thirty
connectors, J1 to J30, of which seventeen are module connectors**.

The blocks are: two ADS1299 8-channel analogue front ends (PIEEG-8 class); the
ESP32-S3-DevKitC-1-N16R8 controller, whose radio is never initialised; an ES8388 codec module
with headphone amplifier; an ADuM4160 USB isolator module carrying the barrier and the host
socket; an ATECC608B secure element; a bq24074-class charger with power path and a MAX17048
gauge; a TPS63020-class buck-boost; a microSD breakout on one-bit SDMMC; the voice-microphone
preamplifier; a room-microphone module with hardware mute; and a 74HC595 shift-register module
for the contact lights.

**Which module lands on which connector is tabulated once, in ICD-EEG-006 section 1**, with
the pinout of every socket and the jumper schedule. That table is not repeated here; a second
copy is a second thing to keep in step, and in package v1 it had already drifted in four
places.

**Where the voice-microphone preamplifier lives.** It is **on the MP-01 module plate,
connected at J21**. The boom carries the bare electret capsule and its screen, on the pigtail
at J18. Package v1, and Rev B of this document, said the preamplifier was on the boom.
`design.py` governs and it is not: J21 is a carrier socket.

**Which preamplifier is not settled, and must not be quoted as settled.** The package-v1
candidate, the MAX9814, has automatic gain control, which RFQ E-14 forbids; disabling it is a
module-dependent modification rather than a configuration. The preferred route is a fixed-gain
part of the MAX4466 class. Until a part is bought and measured, the module is specified **by
interface** in ICD-EEG-006, and AVL-EEG-017 keeps the MAX9814 listed as not approved.

### 2.1 The change that matters: modules are not plugged directly in

Rev A.2 drew module sockets on the carrier and left the geometry to chance. No public
standard fixes the header positions of a PIEEG-8, an ES8388 breakout or a bq24074 module, so
a socket at a chosen coordinate is a guess, and a wrong guess is discovered when the boards
arrive.

Package v2 removes the dependency. **Every module except the DevKit mounts on the printed
module plate MP-01 above the carrier and connects with a keyed 2.54 mm ribbon jumper.**
The carrier sockets are then placed for routing convenience rather than to match an unknown
module footprint, and a different module of the same interface class can be fitted by making
a different jumper. ICD-EEG-006 gives the interface each module must present, the jumper
schedule and the qualification procedure for a substitute.

**Jumper keying is now decided, and is not left to the builder.** At the module end the
jumper terminates in a 2.54 mm shrouded polarised IDC header where the module has one, and
where it does not, pin 1 is marked and the jumper is labelled. At the carrier end every socket
that takes a jumper wears the printed keying shroud **WH-KEY-01**, which is part of the MP-01
print set. ICD-EEG-006 section 6 lists which sockets get one.

The ESP32-S3-DevKitC-1 is the exception: its geometry *is* public, so it is inserted directly
into J6 and J7, on the correct 22.86 mm row spacing.

The cost of this decision is honest: a hand-made jumper set per unit, roughly twenty minutes
of assembly labour, and a 60 mm length limit on the analogue jumper because the ten-way
ribbon has no interleaved grounds. That ribbon is also why RFQ E-04 has been restated:
−100 dB of channel-to-channel crosstalk is not achievable through 60 mm of un-interleaved
ribbon and is about 40 dB below this instrument's own noise floor, so it is not measurable
either. **E-04 is now −80 dB at 50 Hz, measured on the carrier**, with the ribbon's own
contribution characterised once on the first prototype (ECO-EEG-026). A consolidated board
removes the jumper set and the crosstalk argument together, and remains the right answer for a
larger fleet.

### 2.2 The ADS1299 module choice

Unchanged from Rev A.2. The package specifies the module by interface rather than by brand.
Phase 1 buys two PIEEG-8 and, as the reference amplifier for the section 8 comparison test,
one OpenBCI Cyton. ICD-EEG-006 section 2 states the exact interface a substitute must meet:
the digital header must expose SCLK, MOSI, MISO/DOUT, DRDY, CS, START, RESET, CLK, DVDD3V3,
5 V and ground; the analogue header must expose IN1–IN8, SRB1, BIASOUT, BIASIN, AVDD, AVSS
and an analogue reference pin.

---

## 3. Carrier board EEG-CAR-01

### 3.1 What is in the package

**Two revisions are in the tree and only one of them is current.** Rev B is the routed
board, withdrawn from fabrication on 4 September 2026 (ECO-EEG-030) and kept as history.
Rev C is the current carrier: the same circuit at corrected footprints and part numbers,
**unrouted**, released to an external layout contractor. `tools/emit_all.py` writes the Rev C
set and **refuses** to rewrite the Rev B set, because `design.py` has moved to Rev C pads and
regenerating Rev B from it would produce a set whose copper does not reach its own pads.

**Rev C -- the current set, all generated by `tools/emit_all.py`**

| File | Content |
|---|---|
| `kicad/EEG-CAR-01_RevC.kicad_pro` | KiCad project: eight net classes, an assignment for all 156 nets, board minima, DRC severities |
| `kicad/EEG-CAR-01_RevC.kicad_sch` and nine sheets | the **native hierarchical schematic**, KiCad 8. All 211 designators |
| `kicad/EEG-CAR-01.kicad_sym` | the symbol library those sheets are drawn from |
| `kicad/EEG-CAR-01_RevC.kicad_pcb` | the board: placed, netted, 37 footprints locked, **no copper** |
| `kicad/EEG-CAR-01_RevC.kicad_dru` | 37 custom design rules, from `tools/rules.py` |
| `kicad/EEG-CAR-01_RevC-IPC-D-356A.ipc` | the netlist, 156 nets, from the pads alone |
| `kicad/EEG-CAR-01_RevC_BOM.csv` | grouped BOM with a Substitution column |
| `kicad/EEG-CAR-01_RevC_CPL_SMT_top.csv`, `..._CPL_THT_top.csv` | **PROVISIONAL** placement; the files say so on their first line |
| `kicad/EEG-CAR-01_RevC_outline_and_fixed_connectors.dxf` | outline, mounting holes and keep-outs, the isolation strip, thirty connector courtyards |
| `kicad/EEG-CAR-01_RevC_schematic_netlist_check.txt` | the schematic read back and diffed against `design.py` |
| `mech/step/` | 3D bodies: 22 footprint classes bound into the board, the carrier envelopes, MP-01 and its standoffs, the module envelopes |
| `mech/EEG-CAR-01_RevC_collision_check.txt` | the interference report |
| `docs/footprint_audit_RevC.md` | all 211 designators against their part numbers |
| `docs/LAY-EEG-034` | the layout rule sheet, part of the order specification |
| `kicad/RevC_layout_inputs/` | the 51-file handover set with a SHA-256 for every file |

**Rev B -- history. Not a fabrication set, not a quotation basis, not regenerated.**

| File | Content |
|---|---|
| `kicad/EEG-CAR-01_RevB_routed.kicad_pcb` | routed board: tracks on L1 and L4, through vias, reference planes on L2 and L3 |
| `kicad/gerber/*.gbr`, `*.drl`, `*.ipc` | Gerber X2, Excellon 2, IPC-D-356A |
| `kicad/EEG-CAR-01_RevB_DRC_report.txt` | every rule the Rev B rule set contained, measured. **See 3.4 and read it with `..._regraded_ECO-EEG-032.txt`** |
| `kicad/EEG-CAR-01_RevB_regraded_ECO-EEG-032.txt` | the same geometry under the rule set the review asked for: **1 311 occurrences** |
| `kicad/EEG-CAR-01_RevB_BOM.csv`, the two CPLs, the three drawings | as released on 2 September 2026 |
| `schematic/SCH-EEG-005_RevB_schematic_set.pdf` | eight sheets. A picture, not a netlist -- finding 7 |
| `tools/` | the generator, the router, the DRC and this board's source |

### 3.2 The board

This table is the single specification of the bare board. AVL-EEG-017, QP-EEG-010 and
ASM-EEG-007 cite it and do not restate it.

| Property | Value |
|---|---|
| Size | **150.0 × 130.0 mm**, rectangular, no cut-outs, no slots |
| Layers | **four**: L1 signal, L2 reference plane, L3 reference plane, L4 signal |
| Stack-up | mask / 35 µm L1 / prepreg 0.200 / 17 µm L2 / core 1.065 / 17 µm L3 / prepreg 0.200 / 35 µm L4 / mask = **1.60 mm ± 10 %** |
| Material | FR-4, Tg ≥ 150 °C, 1 oz (35 µm) outer copper, 0.5 oz (17 µm) inner copper |
| Finish | ENIG, Au 0.05–0.10 µm over Ni 3.0–6.0 µm |
| Mask / legend | green LPI both sides; white legend both sides |
| Minimum track / clearance | 0.20 mm / 0.20 mm; most conductors are 0.25 mm or wider |
| Electrode-net clearance | 0.35 mm to anything else |
| Vias | **through vias only**: 0.60 mm pad, 0.30 mm **finished** hole, **0.15 mm EXTERNAL annular ring**, tented both sides. No blind, buried, back-drilled, filled or plugged vias anywhere. **The INTERNAL ring is smaller — see the two rows below** |
| Hole dimensions and the tool | **Every hole size in this package is a FINISHED diameter, after plating.** The fabricator selects the drill and **must declare the tool size and the plating allowance it used**, per lot, with the lot documents. Added under ECO-EEG-035: the package previously stated finished diameters only and never named the tool, while quoting an annular-ring figure derived as though the two were the same |
| Internal annular ring | **(0.60 − drilled) / 2, not (0.60 − 0.30) / 2.** The internal ring is measured to the **drilled** hole wall, so it is smaller than the 0.15 mm external figure: about **0.125 mm** at a 0.05 mm total plating allowance and **0.100 mm** at 0.10 mm. QP-EEG-010 IQC-B11 accepts 0.025 mm minimum, so the misregistration budget is (internal ring − 0.025) mm and **falls as the tool grows**. *The reading that the internal ring is measured to the drilled hole is **asserted from standard practice and has not been verified against a copy of IPC-6012**, which this programme does not hold.* IQC-B12's stated 0.125 mm budget is derived from the finished hole and is **superseded** pending that verification |
| Plated hole sizes | **finished diameters**: 0.30 mm (vias), 0.90 mm (JST PH), 1.00 mm (socket strips), 1.20 mm (tactile switches), 1.70 mm (DIN 42802 signal pin) |
| Plated-hole census | 236 plated holes in those five sizes, across 33 through-hole parts |
| Non-plated holes | 4 × 3.2 mm (M3, 6 mm copper keep-out on every layer), 6 × 1.50 mm (DIN retention posts) |
| Mounting | M3 at (5, 5), (145, 5), (5, 125), (145, 125) |
| Zone split | x = 62.0 mm: analogue to the left, digital to the right |
| Reference planes | AGND_REF left of x = 62 mm and DGND right of it, **on both L2 and L3**, tied together by stitching vias |
| Fiducials | three 1.0 mm round fiducials with 3.0 mm mask openings, at (12, 10), (144, 100) and (12, 120) |
| Class | IPC-6012 class 2 (fabrication), IPC-A-600 class 2 (bare board), IPC-A-610 class 2 (assembly) |
| Electrical test | 100 % to the supplied IPC-D-356A netlist |
| Parts | **211 reference designators, 636 pads, 156 nets**; of the designators, 186 are placed parts (153 surface-mount, of which R89 is do-not-populate, and 33 through-hole), and the remaining 25 are 18 test points, 3 fiducials and 4 mounting holes |
| Net census | 156 nets; 620 of the 636 pads carry a net; **11 nets have a single pad** (test points, spare ways and no-connects) and **145 nets have two or more pads**. The netlist figure is 156 and the connectivity figure is 145 -- see the note at the end of 3.4 |
| Process | SMT on the top side only; all through-hole parts on the top side. L4 carries routing, copper and legend, and no parts |
| Conformal coating | **none for Phases 1 and 2.** The board lives inside a gasketed enclosure, and masking 30 connectors and a socketed DevKit costs more than the coating buys. Revisited before Phase 3 if a returned unit shows corrosion |

**A note on the fiducials.** They are new in package v2 and they replace the vision-teach
workaround of Rev B, which asked the placement machine to teach on test-point pads
(ECO-EEG-020). **RUL-EEG-021 section B** records their positions as (12, 10), (144, 100)
and (12, 120), which is where `design.py` places them and what the table above carries. The
register's first issue transcribed them as (8, 8), (142, 8) and (8, 122); that error is
corrected, and `design.py` governs in any case.

**Coordinate convention.** The design source uses a top-left origin with Y increasing
downward, which is the KiCad convention. Gerber, drill and both CPL files use a **bottom-left
origin with Y increasing upward**, which is what CAM expects. The conversion
`y_out = 130.0 − y_design` is applied once, in `tools/gerber.py`, and is stated again in
`kicad/gerber/README_layer_map_and_checksums.txt`. Rev A's CPL used negative Y values with no
stated origin; that is corrected. The constant changed with the board height at Rev C, so any
file generated against `124.0` is superseded.

### 3.3 Layout rules -- how they were applied, not just stated

Rev A.2 gave the rules as a brief for a layout engineer. In package v2 the same rules are
encoded as constraints in the router and re-measured afterwards by the DRC, on the finished
geometry rather than on the routing grid. Rules 2 and 4 below are the home of the star-point
rule and the isolation keep-out for the whole package; every other document cites this
section rather than restating them.

**A citation note, because three documents got it wrong.** This document has sections 1 to 11
and two annexes. **It has no section 13.** The phrase "layout rules that are requirements,
not preferences" belongs to **DSN-EEG-002 section 13** and any citation of it means that
document. The zoning rule, the star-point rule and the isolation keep-out belong to
**DSN-EEG-003 section 3.3**, which is this section, and any citation of them means this one.

1. **Two zones divided at x = 62 mm.** Analogue to the left: the harness socket, the sixteen
   protection networks, both ADS1299 analogue interfaces, the three envelope detectors, the
   comparator, the electrode panel. Digital to the right: MCU, codec, isolator, storage,
   charger, lights. *Verified:* the DRC counts digital nets inside the analogue zone and
   analogue nets outside it and reports zero of each. One signal crosses by design --
   CMP_RAW, the comparator output, which must reach a 3.3 V GPIO; it does so through R83 and
   the D23 clamp.

2. **AGND_REF is the analogue 0 V mid-rail, not ground.** AVDD = +2.5 V and AVSS = −2.5 V are
   generated on ADS1299 module #1 and brought onto the carrier at J23. AGND_REF is poured on
   **L2 and L3** over the whole analogue zone; L1 and L4 are left free for routing, which is
   the point of going to four layers. It joins DGND at **R90 only**; HARN_SHIELD joins DGND at
   **R91 only**. Both are 0 Ω 0603 parts, not copper bridges, so either can be lifted for a
   leakage measurement and refitted. *Verified:* the DRC counts the bridges and reports one
   of each.

3. **Every electrode net is routed on L1 with the reference plane continuous beneath it**, at
   0.35 mm clearance to any other net rather than 0.20 mm. The protection network for each
   input is placed in a straight line -- resistor, clamp, filter capacitor -- from the harness
   towards the module. On two layers this rule and rule 2 were in direct conflict, because the
   only available plane was also the only second routing surface. On four layers they are not.

4. **The isolation barrier is on the module, and the carrier stays out of its way.** The
   ADuM4160 module carries the 2.5 kV barrier; no carrier copper crosses it because nothing on
   the carrier is on the host side. What the carrier must guarantee is that no copper sits
   *under* the module's host half, so the strip **x ≥ 141.0 mm, y = 2.0 to 22.0 mm** is free of
   copper on **all four layers** and is marked on the legend and the fabrication drawing.
   *Verified:* the DRC reports no copper inside the strip on any layer.

5. **USB_DP and USB_DN** are a 0.30 mm pair on 0.35 mm spacing, routed on L1 directly over the
   DGND plane on L2 -- about 95 Ω differential on this stack-up. No coupon and no impedance
   test are required, and the fabrication drawing says so explicitly so that nobody quotes for
   one.

6. **Envelope decoupling** is within 3 mm of pins 4 and 11 of each OPA4376, and the three
   envelope outputs run directly to J4 pins 4–6.

7. **No via inside the analogue module connector outlines** (J2, J4, J23, J29). *Verified.*

8. **Non-plated holes carry no copper and no solder-mask opening**, and are supplied in a
   separate drill file. This closes ECO-EEG-012: in Rev A the six DIN retention holes were
   declared on `*.Cu` and `*.Mask`, which would have plated them and connected the
   touch-proof EMG socket bodies to the analogue reference pour.

9. **Through vias only.** Every via passes through all four layers. No blind, buried,
   back-drilled, filled or plugged via is used anywhere on the board, so the four-layer stack
   is quotable at any fabricator's standard price and there is no sequential lamination.

### 3.4 How the routing was produced, what that means, and what happens to Rev C

**Rev C has no routing and this section has no result to transcribe for it.** What follows is
the Rev B result, kept because it is the measured state of the data in the tree, and then what
Rev C will be graded on when it comes back.

The board was routed by the programme's own constraint-aware maze router
(`tools/router.py`): a Dijkstra search on a 0.1 mm grid over four layers with a via cost, the
rules of 3.3 encoded as hard keep-outs and zone masks, a rip-up-and-retry pass for connections
that the first pass could not make, a via-push pass that moves any via that ends up inside
another net's clearance, and reference planes built as real polygons on L2 and L3 with
four-spoke thermal reliefs on same-net through-hole pads. L1 and L4 carry signals only.

**This must be read as what it is.** The geometry is measured, not asserted: every clearance
is taken between the real polygons the Gerbers are written from. The result is transcribed
below from `kicad/EEG-CAR-01_RevB_DRC_report.txt`, which is the authority for it. This
paragraph is not the authority: if the table below and the report ever differ, the report is
right and this document is corrected.

| What the DRC measured | Value | Rule |
|---|---|---|
| Board | 150.0 × 130.0 mm, four copper layers | -- |
| Track segments | 3 745 | -- |
| Through vias | 552 | -- |
| Pour islands | 4 -- **each reference plane is one continuous island per net, on both L2 and L3** | one island per net per plane |
| Smallest clearance on L1 | 0.260 mm | 0.20 mm |
| Smallest clearance on L2 and L3 | 0.285 mm | 0.20 mm |
| Smallest clearance on L4 | 0.275 mm | 0.20 mm |
| Narrowest conductor | 0.20 mm | 0.20 mm minimum |
| Connections the router had to relax | **169** -- 36 narrower than the 0.25 mm preferred width, 133 at full width with a reduced gap | every one at or above the 0.20 mm minimum conductor and gap |
| Smallest plated hole | 0.30 mm | 0.30 mm |
| Non-plated holes | 10 | -- |
| Digital nets inside the analogue zone | **0 zone crossings** | 0 |
| AGND_REF-to-DGND bridges | **1** (R90) | exactly 1 |
| HARN_SHIELD-to-DGND bridges | **1** (R91) | exactly 1 |
| Duplicate copper | **0** segments, **0** via positions | 0 |
| Nets checked for connectivity | 145 | -- |
| Nets fully connected | **145** | 145 |
| Nets with no copper at all | **0** | 0 |
| **Violations** | **0** | 0 |

**There are no violations.** The report's own line is: "VIOLATIONS: 0 -- none.  The board
passes every rule listed above." Every net the connectivity check grades is one connected
copper island, none is left without copper, and the two electrode-clearance vias at 0.328 mm
that earlier issues of this section recorded are gone. There are no clearance violations of
any kind, and no track width, annular ring, plated-hole size, board-edge, non-plated-hole,
isolation keep-out or via keep-out violation. In particular the isolation strip at **x ≥
141.0 mm, y = 2.0 to 22.0 mm is clear of copper on all four layers**, and that is said here
because the report says it: the keep-out is now enforced against copper *edges* rather than
track centrelines, which is what earlier revisions got wrong. How the board was brought to
this state is recorded in **ECO-EEG-016 section 2B**.

**What closing it cost: 169 relaxed connections.** On 169 pad-to-pad connections the router
had to take the tightest geometry the rules allow -- 36 with a conductor narrower than the
0.25 mm preferred width, and 133 at full width with a reduced gap. Every one is at or above
the 0.20 mm minimum conductor and the 0.20 mm minimum gap, so none of them is a violation,
and none of them is comfortable either. The route this document carried before it closed
relaxed 19. **A board that closes at minimum geometry is not the same board as one that
closes at preferred geometry, even when every rule passes**, and those 169 places are where
the layout reviewer starts. The DRC report lists them by net and by pad pair, split into the
two kinds, so a reviewer can go straight to where the router had to squeeze. The list counts
*connections*; the `tracks below 0.25 mm` figure under MEASURED counts *segments*, and one
connection is many segments, which is why the two numbers differ.

**The Rev B fabrication data is WITHDRAWN FROM FABRICATION and no board is ordered from it.**
It met the three conditions ECO-EEG-016 section 3 sets as the fabrication-release gate -- zero
DRC violations, every net one connected copper island, both inner planes continuous under the
analogue zone -- and that was not enough. An external layout engineer read
`kicad/EEG-CAR-01_RevB_routed.kicad_pcb` between 3 and 5 September 2026, declined the paid
review and advised a redesign from the schematic; the programme accepted that on 4 September
2026. His seven findings are recorded in **ECO-EEG-016 section 2, ECO-EEG-030**, and six of
them are rules this DRC was never given, so a report at zero violations was a report against
an incomplete rule set. The data above stays in the tree as history and is not deleted. It is
not a quotation basis and nothing may be ordered from it. No document in this package may
describe it as released for fabrication or for review, and no document may state a DRC result
without checking the report, as this section has.

**Why the DRC counts 145 nets and section 3.2 counts 156.** `design.py` declares **156 nets**
across 211 reference designators and 636 pads, 620 of which carry a net. Eleven of those 156
nets have a single pad -- test points, spare ways and no-connects -- and a net with one pad has
nothing to join, so `tools/netcheck.py` does not check it. The connectivity check therefore
reports on **145 nets, and all 145 are fully connected**. Both figures are correct for what
they count. **156 is the netlist figure**: it is what the IPC-D-356A file and the 100 % bare-board
electrical test of section 3.2 are written against. **145 is the connectivity figure**: it is
what the DRC report grades and it can never exceed 156. Any document quoting either number
states which of the two it is quoting.

**And the rule set was incomplete, which is the part that matters.** The report above says
"VIOLATIONS: 0 -- none. The board passes every rule listed above", and it is correct: it is
correct about the twelve rules it had. Six of the seven findings the external reviewer made
are rules it did not have, and there was no way for a report to say so. **ECO-EEG-032 encoded
them and regraded the same released geometry**; the result is
`kicad/EEG-CAR-01_RevB_regraded_ECO-EEG-032.txt`:

| Finding | Rule | Occurrences in the released Rev B routing |
|---|---|---|
| 1 | vias inside an SMD pad | **67** |
| 2a | dangling track ends | **5** |
| 2b | redundant copper loops outside a plane | **221**, on 22 nets |
| 3 | angle below 90 degrees between two segments | **171** |
| 3 | segments off a 0/45/90/135 degree axis | **158** |
| 4 | off-centre pad entries | **299** |
| 5 | conductors under their class minimum | **322** |
| 5 | net classes on a forbidden layer | **50** |
| 5 | vias on a class that forbids them | **18** |
| | **total** | **1 311** |

The Rev B report is not withdrawn. It measured what it was asked to measure.

**What Rev C is graded on when it comes back.** The rule set is `tools/rules.py`, the sheet the
contractor works under is **LAY-EEG-034**, and the machine-readable half is
`kicad/EEG-CAR-01_RevC.kicad_dru`. On return this programme runs `tools/drc.py` with
`tools/drc_geometry.py` over the returned geometry -- the twelve original rules **and** the six
above, including the two KiCad has no constraint for and cannot check: the 90-degree angle
floor and pad-centre entry. The three conditions of the fabrication-release gate in ECO-EEG-016
section 3 are then measured on that geometry, and the placement review of RFQ-EEG-002A must
already have closed, before routing was confirmed.

An autorouter has no opinion about return paths, coupling or manufacturability beyond the
rules it was given, and passing every rule it was given did not make the board reviewable.
**The routing is no longer produced here.** Rev C is the same circuit at corrected footprints
and part numbers, with **no routing of its own**: placement and routing are bought from an
external layout desk, and `tools/router.py`'s remaining roles are to hold and enforce the rules
so that a returned board can be graded against them, and, optionally, to produce an in-house
reference route for comparison. **RFQ-EEG-002A is re-scoped again**, from *review this routing*
to **review the layout contractor's PLACEMENT of Rev C**, taken before routing is confirmed and
delivered as a written findings list by net, pad pair and coordinate. The scope is defined in
ECO-EEG-030 and the rules the contractor works under are **LAY-EEG-034**.

---

## 4. Printable and mechanical parts

The part-identifier register PARTS-EEG-019 is now the single authority for every part number
in the package. It exists because Rev A used `HM-xx` as two overlapping namespaces -- figure
labels and part numbers -- with the result that **HM-07 named the boom microphone arm in
DSN-EEG-002 section 10 and the battery hatch in DSN-EEG-003 section 4 and in the STL set**.
A manufacturer printing "HM-07" would have produced a different part depending on which
document was open. Figures are now `FIG-nn` and `HM-xx` is reserved for parts.

**The enclosure and the module plate grew with the board.** POD-P1 and MP-01 are generated by
`tools/mech_gen.py` from the same `BOARD_W` and `BOARD_H` as the carrier, so they follow the
outline change automatically; the figures below are the current ones.

| File | Part | Bounding box (mm) | Volume (cm³) | Process |
|---|---|---|---|---|
| `HM-01_frame_monocoque.stl` | HM-01 helmet frame | 191.1 × 229.6 × 158.0 | 133.6 | MJF PA12 |
| `HM-02_brow_pad.stl` | HM-02 brow pad | see MECH-EEG-020 | see PARTS-EEG-019 §2 | MJF PA12 or TPU |
| `HM-04_electrode_assembly_body.stl` | HM-04 electrode assembly, 8 fitted + 2 spare = 10 per kit | 12.4 × 12.4 × 18.0 | 1.9 | MJF PA12 |
| `HM-08_battery_hatch.stl` | HM-08 quarter-turn hatch (was HM-07 in Rev A) | 48.0 × 36.0 × 6.5 | 6.9 | MJF PA12 |
| `HM-09_service_key.stl` | HM-09 cup service key, one per operator, **not a kit item** | 17.9 × 17.9 × 40.2 | 3.9 | MJF PA12 |
| `MP-01_module_plate.stl` | MP-01 module mounting plate | **146.0 × 126.0 × 3.0** | see PARTS-EEG-019 §2 | MJF PA12 |
| `POD-P1_prototype_enclosure_base.stl` | POD-P1 base | **163.0 × 143.0 × 58.0 external; 158.0 × 138.0 × 55.5 internal** | see PARTS-EEG-019 §2 | MJF PA12 or FDM PETG |
| `POD-P1_prototype_enclosure_lid.stl` | POD-P1 lid, with a 2.0 mm spigot | **163.0 × 143.0 × 6.0** | see PARTS-EEG-019 §2 | MJF PA12 or FDM PETG |
| `FIT-01_fit_test_coupon.stl` | FIT-01 fit-test coupon, printed with every batch, bores 9.20 / 9.35 / 9.15 mm | 60.0 × 24.0 × 10.0 | see PARTS-EEG-019 §2 | same process as the batch |
| `CASE-00_foam_layer_1.dxf` | CASE-00-01 foam layer 1 of 7, all nine bays, helmet bay at the 181 × 220 mm shelf opening | 516.0 × 390.0 sheet, 25 thick, 1:1 in mm | -- | die-cut or laser-cut |
| `CASE-00_foam_layer_2.dxf` | CASE-00-02 foam layer 2 of 7, all nine bays, helmet bay at the full 197 × 236 mm | 516.0 × 390.0 sheet, 25 thick, 1:1 in mm | -- | die-cut or laser-cut |
| `CASE-00_foam_layer_3.dxf` | CASE-00-03 foam layer 3 of 7, five bays: helmet, headphones, pod, consumables, cables | 516.0 × 390.0 sheet, 25 thick, 1:1 in mm | -- | die-cut or laser-cut |
| `CASE-00_foam_layer_4.dxf` | CASE-00-04 foam layer 4 of 7, two bays: helmet, headphones | 516.0 × 390.0 sheet, 25 thick, 1:1 in mm | -- | die-cut or laser-cut |
| `CASE-00_foam_layer_5.dxf` | CASE-00-05 foam layer 5 of 7, helmet bay only | 516.0 × 390.0 sheet, 25 thick, 1:1 in mm | -- | die-cut or laser-cut |
| `CASE-00_foam_layer_6.dxf` | CASE-00-06 foam layer 6 of 7, helmet bay only | 516.0 × 390.0 sheet, 25 thick, 1:1 in mm | -- | die-cut or laser-cut |
| `CASE-00_foam_layer_7.dxf` | CASE-00-07 foam layer 7 of 7, helmet bay only | 516.0 × 390.0 sheet, 25 thick, 1:1 in mm | -- | die-cut or laser-cut |

The seven foam files are the **CASE-00 Rev C** stack of PKG-EEG-015 section 2.2, written by
`tools/mech_gen.py` `foam_dxf()`; the two Rev B sheets this table listed until the correction
of 2 September 2026 are withdrawn and deleted from `mech/`, because 50 mm of foam cannot hold
a 158 mm helmet. A bay is
drawn in a file only where the schedule cuts it through that layer, so the seven are not
interchangeable. **They are drawn and not released for cutting**: the 516.0 × 390.0 mm sheet is
the Peli 1560's published internal footprint minus 2 mm on each plan axis, and no shell has been
bought or measured -- PKG-EEG-015 section 3.2 re-draws the sheet to the measured footprint before
any foam is cut.

STEP files and dimensioned 2D drawings accompany each STL in `mech/step/` and
`mech/drawings/`, and MECH-EEG-020 is the drawing set. Rev A supplied STL only, from which no
one can dimension anything.

**MP-01.** An 8 mm solid border, a field of 12 × 3 mm jumper slots on a 16 × 7 mm grid, Ø2.7 mm
M2.5 clearance holes between the slot rows for the module fixings, one 31 × 61 mm opening over
the DevKit, and four Ø3.4 mm holes on the carrier mounting pattern.

**The carrier-to-plate standoff is M3 × 18 mm nylon hex, female-female, four off, with eight
M3 × 6 nylon pan screws.** Two documents previously dimensioned it and disagreed; 18 mm is the
figure, and it is load-bearing for safety, not only for fit: the slant path from carrier
copper, over the edge of the isolation keep-out and up the standoff to any host-side conductor
on MP-01 is at least 18 mm, which is more than twice the 8 mm the safety case asks for. That
closes RISK-EEG-011 SR-08. The full stack budget, which comes to 49.1 mm against 55.5 mm of
internal depth with 6.4 mm of margin, is tabulated once in ICD-EEG-006 section 4.

**POD-P1 panel openings.** The three response and stop buttons are 6 mm tactile switches with
12 mm coloured caps on extenders behind **13.0 mm openings on a 14 mm pitch** at y = 76, 90 and
104 mm on the right-hand wall. The host USB connection is **a socket, not a captive cable**:
the USB-C receptacle on the ADuM4160 module is presented through a gasketed aperture, and the
kit ships the two cables of RFQ A-07, one of which is the host lead. The cable gland and the
captive lead WH-08 are deleted from the Phase 1 build and are a Phase 2 item for the helmet
shell. **The pod carries no indicator light:** all eight lights are in the helmet and the pod's
state is read from the session runner, so the M-02 LED opening is withdrawn.

---

## 5. Firmware FW-EEG-001

`firmware/` now contains the build system, the configuration, the partition table, the
provisioning script and the host verification tool, not only `main.c`. FW-EEG-001 Rev D is
the specification, and it is the home of the public-key fingerprint definition that six other
documents cite.

**Corrected 2 September 2026.** Until that date this section said, plainly, that the firmware
*had never been compiled against a real ESP-IDF installation and had never run on hardware*.
The first half is no longer true. **The firmware is built:** ESP-IDF v5.2.5, target esp32s3,
and `firmware/release/` holds `bootloader.bin`, `partition-table.bin`, `ota_data_initial.bin`
and `eeg_field_kit.bin` with a `manifest.json` recording the SHA-256 of each; the linked image
is 405,245 bytes. It has also **run once, in an emulator**: `firmware/release/qemu_boot.log` is
a full boot cycle under `qemu-system-xtensa -M esp32s3` in which the second-stage bootloader
reads this partition table, the app is loaded from the factory slot, `app_main()` runs, the
microSD and ES8388 bring-up paths degrade gracefully when the peripherals do not answer, and
the PSRAM ring-buffer allocation failure is caught and aborted where FW-D13 says it should be.

**The second half is still true, and it is the half that matters: the firmware has never run
on hardware.** QEMU's esp32s3 machine has no octal PSRAM, no microSD, no ES8388 and no
ADS1299, so not one register value, daisy-chain order or SPI timing in this design is
evidenced by that run. A build is not a bring-up. Five drivers are still stubs (ES8388,
SDMMC, ATECC608B, MAX17048, the envelope onset detector). The pin map has been corrected
(ECO-EEG-009) and now avoids GPIO35, 36, 37 and 45. Completing the stubs and getting a clean
enumeration on three operating systems is the first task of the firmware volunteer or an ODM
line item, and TST-EEG-004 step T5 is its acceptance test.

Three firmware facts a manufacturer needs, each stated with its exception in the same
sentence:

* **The contact-light driver is written, and no light has ever been lit.** Corrected
  2 September 2026: until that date `lights_write()` and `lights_task()` were on/off only and
  this bullet said the bicolour scheme was not coded, so E-27 was not met and TST-EEG-004 step
  T11 could not pass. `lights_task()` reads the converter's positive-side
  lead-off comparator at **two thresholds** and alternates the green and red phases: a site
  that trips neither is green, one that trips only the sensitive threshold is amber, and one
  that trips both is red. `LIGHT_PHASE_HZ` is 240, but the half-phase quantises to the
  FreeRTOS tick, so the **actual alternation is about 250 Hz**, which is what E-27's "above
  100 Hz" asks for and what T11's colorimeter reads. **Corrected again 2026-09-02 (FW-D17):**
  this bullet read that the driver used both halves of the lead-off word and that red was
  unreachable until the N-side excitation was enabled. Enabling it would not have helped.
  **The montage is single-ended** -- J2 carries IN1 to IN8, one shared `SRB1` and `BIASOUT`
  -- so `LOFF_STATN` has no per-site electrode to report on, and with `SRB1` closed all eight
  N bits would have reported the one shared reference. The two-threshold sweep is what this
  hardware can actually support. One caveat stands and is not rounded away: no unit exists,
  so **T11 has not been run**, and the two `COMP_TH` values are the datasheet's endpoints
  rather than measured ones.
* **The eFuses are not burned on the Phase 1 prototypes.** Secure boot and flash encryption
  are enabled from Phase 2, so the two prototypes run unsigned images and TST-EEG-004 step T25
  is marked "Phase 2 onward" and is not a Phase 1 gate.
* **The PSRAM ring buffer is 6 MB, not the 12 MB that three minutes at 1000 Hz would need**,
  which is 126 seconds of raw samples (124 s counted over the framed stream). RFQ F-06 is therefore relaxed to 90 seconds of ring plus unlimited
  backfill from the microSD copy (ECO-EEG-025), rather than being quietly missed.

**End-of-line flashing goes through the DevKitC-1's own UART USB-C port**, which carries the
auto-reset circuit (DTR and RTS to EN and IO0) on the DevKit itself and is reachable through
the MP-01 opening. The carrier's J26 is a 1×6 console and recovery header and **cannot** enter
download mode, because GPIO0 is committed to LED_SR_LATCH (ECO-EEG-009) and J26 way 6 is a
spare, `NC_GPIO0`. No JTAG or SWD connector is fitted anywhere on the carrier; the ESP32-S3 is
programmed over UART0 and its native USB. RFQ E-28 has said so since RFQ-EEG-001 Rev D and
Rev E carries it unchanged, and the "E-28
deviation" notes that four documents carried against a 2×5 1.27 mm header are withdrawn
along with the header.

---

## 6. Production test TST-EEG-004 Rev C

Now a standalone controlled specification with fixtures designed in JIG-EEG-009 Rev C.
**TST-EEG-004 Rev C owns the step numbering for the whole package**; this document and every
other cites T-numbers from it and never invents one. Rev C runs **T00 to T29**.

It keeps the steps of Rev A and adds the ones package v2 needs: bare-board electrical test,
incoming inspection of modules, star-point verification with R90 lifted, insulation
measurement across the USB barrier, charge-interlock verification, contact-light colour
verification in all three states, one-bit SDMMC throughput at 1000 Hz, and a leakage
measurement standing in for patient auxiliary current. It carries a requirements-to-test
traceability matrix, so any mandatory requirement with no test is visible rather than assumed.

Two points of method that a test house must not get wrong:

* **The per-unit isolation test is a 500 V DC insulation-resistance measurement across the
  barrier, not a hipot.** The 2.5 kV RMS type test is the isolator module supplier's
  certificate and is checked once, at incoming inspection. No production station applies
  2500 V AC to a unit.
* **The fixtures are FIX-01 to FIX-04**, with sub-assemblies lettered FIX-01/A to FIX-01/G,
  FIX-02/A to FIX-02/D, FIX-03/A onwards and FIX-04/A to FIX-04/D. **The fixture table is
  TST-EEG-004 Rev C section 6.1**, which is its only home; JIG-EEG-009 Rev C designs the
  fixtures against those same letters and uses no others. The bare letters H-A, H-B and H-C
  and the names CPL-V and CPL-R are withdrawn. Contact-light colour is read by a
  TCS34725-class colorimeter head, FIX-01/E, taking the red-to-green ratio at each site.

A new type test is added at Rev C: **RFQ E-29 caps the headphone output at 100 dB SPL** at any
commanded level, measured on an artificial ear, with the firmware clamping the codec volume
register to the value measured at calibration. The requirement exists because the calculated
full-scale output is about 110 dB SPL. It is **step T28 of TST-EEG-004 Rev C**, listed among
the type tests in **TST-EEG-004 Rev C section 14** and run once per lot on one unit, not on
every unit.

---

## 7. What a manufacturer can and cannot do with this package

| Question | Answer | Why |
|---|---|---|
| Can you fabricate the bare board? | **No. There is no current fabrication data at all.** | Rev B's Gerbers, drill files, IPC-D-356A netlist and drawings are complete, checksummed and **withdrawn from fabrication** (ECO-EEG-030): a layout engineer read the board, declined the review and advised a redesign. **Rev C is unrouted** -- its placement and routing are bought, and what exists for it is the layout input set in `kicad/RevC_layout_inputs/` and the rule sheet LAY-EEG-034. Nothing may be quoted or ordered from Rev B |
| Can you assemble it? | **Yes, firm** | BOM with manufacturer part numbers, SMT and through-hole CPL, paste layer, assembly drawing, work instructions |
| Can you print the mechanical parts? | **Yes** | STL, STEP and dimensioned drawings for every part. The foam is a separate answer: seven DXF layer files are drawn and **not released for cutting** until the case shell is measured -- section 4 and PKG-EEG-015 section 3.2 |
| Can you build the harness? | **Yes** | WH-EEG-008 gives a complete from-to wire list, materials, tooling and test |
| Can you provision and test a unit? | **Yes**, once the firmware image exists | TST-EEG-004 Rev C and JIG-EEG-009 Rev C are complete; the image is programme work |
| Can you ship a working prototype for software development? | **Yes for the hardware**; the firmware stubs are programme work | the prototype enumerates only once the stubs are done |
| Can you ship a unit for use on a participant? | **No** | the safety review has not been performed. It gates Phase 2 |

Quantities: Phase 1 is **2 prototypes**, Phase 2 is **10 kits**, Phase 3 is **10 to 40 further
kits, 25 to 50 in total**.

---

## 8. The re-issued RFQ

| RFQ | Scope | Sent to |
|---|---|---|
| **RFQ-EEG-002A -- layout review** | Review the supplied routing against the rules in section 3.3 -- the DRC now reports nothing to close, so the work is judgement rather than repair, starting with the 169 relaxed connections of section 3.4 -- correct what is wrong, and sign it off. Deliver a corrected board file, corrected Gerbers and a review note. One correction round. This replaces the *routing* scope of Rev A.2, because the board is now routed. Note that the board is four layers and 150 × 130 mm as of Rev C | JLCPCB layout portal, Makerfabs, Best Technology, any freelance layout engineer |
| **RFQ-EEG-002B -- manufacturing** | From the released fabrication package: 2 carriers, then 10, then 10–40; module procurement or consignment; MJF printing; harness assembly; provisioning and TST-EEG-004; kitting | HongRong, Elecrow, Regulus, PCBSync, Best Technology, Leiton, Eurocircuits, myProto, Dekimo |

Sponsorship: JLCPCB's open-source programme is applied to for the Phase 1 carrier fabrication
and prints, with the CC BY-SA repository as the application's centrepiece.

### 8.1 What the nine houses actually said

These are the replies to the first approach, in one line each, carried forward from
DSN-EEG-003 Rev A.2 Table 1. They are kept because they are the only commercial evidence
either package holds, and because the second column is the reason this design is
module-on-carrier rather than a single board of bare silicon.

| Company | Reply, in one line | Can do from a finished package | Follow-up |
|---|---|---|---|
| Leiton (Berlin) | No design capability; manufactures only from finished data | PCB + assembly | Re-send now that routed Gerbers exist |
| Regulus (Taiwan) | Scope beyond EMS; ISO 9001 not 13485; will reconsider PCBA and box-build once Gerber/ODB++, BOM, CPL, firmware and a validation plan exist | PCBA, box-build, test | Re-send the full production package; correct our ISO 13485 assumption in the contact list |
| HongRong (Shenzhen) | Good fit for PCB, PCBA, enclosure and kit; asks whether layout is done | All of it except layout | Answer: the carrier is routed, on four layers, and passes its DRC with zero violations; the routing is not yet reviewed by a layout engineer; send the package |
| Elecrow (Shenzhen) | Declines custom design and EEG; offers production, firmware flashing, test and packaging from a finalised design | Production and packaging | Send the package; ask for the PIEEG introduction |
| Makerfabs (Shenzhen) | ODM: schematic/layout/samples, files owned by customer; **Phase 1 design plus two samples US$20–30k** | Everything, at a price | Ask them to quote review of the supplied carrier file only -- a fraction of the blank-sheet number |
| JLCPCB | Layout portal, PCBA, 3D printing; will not source headphones, electrodes or cases; has a sponsorship programme | PCBA, enclosure prints, layout | Upload the carrier file to the layout portal; apply for sponsorship with the open-hardware repository |
| Best Technology / EBest | Reviewing with engineering; will quote within three weeks; sponsorship to be evaluated | Layout, PCBA, kit assembly | Send the package now so their review is of real files |
| RayPCB → PCBSync | Acquired; Stan will contact | PCB + assembly | Update contact to stan@pcbsync.com; send the package |
| NextPCB | Automated portal reply | Portal PCBA only | Drop from the mailing; portal upload now that the board is routed |

**Why this table governs the architecture.** Makerfabs' US$20–30k is a blank-sheet ODM
quotation for Phase 1 design plus two samples. The programme's entire Phase 1 materials
and assembly budget, at the two-unit break, is about EUR 4 300 including the one-off
placeholders (internal costed BOM Rev C, Kit summary). A blank-sheet design engagement is
therefore between four and seven times the whole of Phase 1, and that -- not a preference
for modules -- is why the instrument is built from breakout modules on a carrier the
programme routed itself. Six of the nine houses will work from a finished package and only
two will design one. **The package had to become the thing that is finished.**

Two of the nine replies are now out of date in the programme's favour: Leiton and NextPCB
both said "come back when it is routed", and it is routed.

---

## 9. Engineering changes

**This is an index, not the register.** ECO-EEG-016 section 2 is the register of record and
carries the finding, the reasoning, the verification and the impact of every change; where it
and this index differ, the register governs. ECO-EEG-016 is a **document** number and is not
also a change number: the change previously numbered ECO-EEG-016 is now **ECO-EEG-018**, so
that nothing shares a number with the register itself.

Fourteen changes, ECO-EEG-001 to ECO-EEG-014, are the carrier defects found in Rev A. Four of
them were blocking: the board as released in package v1 could not have been built.

| ECO | What was wrong in Rev A | Severity | What the current board does |
|---|---|---|---|
| 001 | LED1–LED8 had no driver: the 74HC595 outputs were not brought to the carrier | **blocking** | J19 widened to 1×16; R70–R77 added; bicolour phase scheme defined |
| 002 | No source for DVDD3V3; charger SYS, DevKit 5 V and both module supplies unconnected | **blocking** | J25 buck-boost socket, V5V rail, C70–C74 |
| 003 | No charge input; VBUS_CHG had one pad | **blocking** | J24 charge-only pigtail, F1 PTC, D24 TVS, VBUS_DET divider |
| 004 | Envelope filter not in circuit: op-amp B inverting input unconnected | **blocking** | OPA4376 quad, all four loops closed |
| 005 | BAT54S fitted the wrong way round in the rectifier | major | pin 3 to the op-amp output |
| 006 | Sallen-Key Q = 0.5 gave −3 dB at 31 Hz, outside E-11 | major | 22 k / 100 nF / 220 nF → 48.8 Hz, Q = 0.74. **Superseded 2 September 2026** by the C0G rescale of ECO-EEG-019's second half: **215 kΩ with 10 nF and 22 nF, f0 49.9 Hz**, Q unchanged at 0.742. The values in this row are no longer what is fitted |
| 007 | No mounting holes, although the spec sheet promised four M3 | **blocking** | MH1–MH4 with a 6 mm copper keep-out |
| 008 | J6/J7 row spacing 22.0 mm; the DevKit is 22.86 mm | **blocking** | 22.86 mm |
| 009 | Shift-register lines on GPIO35/36/37 -- the octal PSRAM on the -N16R8 | **blocking** | GPIO41/42/0; SD dropped to one-bit; 35/36/37/45 left open |
| 010 | ENV_CMP, MIC_BIAS and SPARE1/2 dangling; no room-microphone connector | major | U7 comparator, J28, protected spares to J22 |
| 011 | No analogue reference pin at the module connectors; both modules' rails hard-paralleled | major | AGND_REF on J23.4 and J29.4; R92/R93 separable |
| 012 | Non-plated holes declared on copper and mask | major | no copper, no mask, separate NPTH drill file |
| 013 | 2×10 analogue connectors had no escape route for the inner row | **blocking** | split into a 1×10 signal socket and a 1×6 rail socket per module |
| 014 | Eight digital light lines ran through the electrode harness | major | harness split into a 12-way screened electrode cable and a 10-way light cable |

Two of these -- 001 and 014 -- together resolve the finding Rev A.2 recorded as "the 74HC595
light driver and the harness LED lines are digital signals routed through the analogue
harness" and then accepted. It should not have been accepted. It is now fixed.

Three changes are structural, and one of them carries the geometry change of Rev C.

| ECO | What it changes | Severity |
|---|---|---|
| 015 | Part identifiers meant two different things: `HM-xx` was both a figure label and a part number, and HM-07 named two different parts. PARTS-EEG-019 is now the single register | major, documentation |
| 017 | Lithium shipping was never mentioned. RFQ S-09 is new, REG-EEG-012 section 3 states the obligation and PKG-EEG-015 section 7 gives the procedure for both legs | major, compliance |
| 018 | The routing is now supplied, so RFQ-EEG-002A becomes a review rather than a routing job. **Doing the routing grew the carrier from 130 × 124 mm to 150.0 × 130.0 mm and took it from two layers to four**, for the reasons given under "Why this revision exists"; POD-P1 and MP-01 follow the outline | scope, and a design change |

Nine changes come from the cross-document audit of 1 September 2026. Each is a real design
change and none is cosmetic.

| ECO | What it changes | Severity |
|---|---|---|
| 019 | C1–C16 are C0G and the package's part number was not: `GCM188R71H103KA37D` is an X7R part and is replaced by **`GCM1885C1H103JA16D`** (10 nF, C0G, 50 V, 0603). A 100 nF C0G in 0603/50 V is not a stocked part, so C21/C41/C61 were specified as X7R with a stated 15 % capacitance tolerance over temperature and the filter-corner tolerance in TST-EEG-004 was widened to match. **Corrected 2 September 2026: the network stopped asking for 100 nF.** The Sallen-Key capacitors scale down by ten and its resistors up by ten -- C21/C41/C61 are now the same **10 nF C0G `GCM1885C1H103JA16D`** the board already buys sixteen of as C1-C16, C22/C42/C62 are **22 nF C0G `GCM1885C1H223JA16D`**, and R25/R26 and their two sibling pairs are **215 kOhm** -- which leaves f0 at 49.9 Hz and Q at 0.742 and holds the corner inside 47.5 to 52.5 Hz on C0G's ±5 %. **E-11 is met in both halves**; the widened TST tolerance is no longer the reason it passes | major |
| 020 | Three 1.0 mm fiducials with 3.0 mm mask openings are added to the carrier; the vision-teach workaround is withdrawn | minor |
| 021 | R94 and R95, 4.7 kΩ to DVDD3V3, are added on SDA and SCL. Depending on whatever the modules happen to carry is not a design | major |
| 022 | R85 changes from 56 kΩ to 150 kΩ, giving 3.0 V at VBUS = 5 V, above the 2.48 V input-high threshold of a 3.3 V ESP32-S3 input. The 1.79 V of Rev B would not reliably assert the first of the two S-01 interlocks | major |
| 023 | U7 is powered from DVDD3V3 and DGND instead of AVDD and AVSS, so its output swings 0 to 3.3 V into GPIO3 with full margin and D23 becomes a belt-and-braces clamp. Its inputs are re-referenced to a DVDD3V3/2 divider and the envelope is AC-coupled into it. **The safety and layout reviewer must check this change specifically** | major |
| 024 | Single-fault DC current at the patient was **calculated at 53.2 µA against the 50 µA limit of S-02, so S-02 was not met.** Raising R1–R16 from 47 kΩ to 68 kΩ gives 36.8 µA, moves the corner to 234 Hz (−0.75 dB at 100 Hz) and raises total input noise to 0.31 µV, still inside E-03; E-10 moves from its ±0.5 dB branch to its ±1.0 dB branch, which that requirement already states for this case. **APPLIED 2 September 2026.** `design.py` fits **68 kΩ** at R1–R16 today, the same 0603 footprint on the same nets, so the board did not move; **S-02 is met at 36.8 µA**. Corrected on the same date: this row read "the ECO is open" and "47 kΩ is fitted on the Phase 1 prototypes". What is still open is the **safety sign-off** -- SR-01 is closed in the design and has not been reviewed -- and the measurement, which no unit exists to make | **was blocking for use on a person; now open for sign-off** |
| 025 | RFQ F-06 is relaxed from three minutes of ring buffer to **90 seconds plus unlimited backfill from the microSD copy**, because 12 MB of ring in 8 MB of PSRAM is impossible and the fitted 6 MB is 126 seconds | major |
| 026 | RFQ E-04 is restated from −100 dB to **−80 dB at 50 Hz, measured on the carrier**, with the ribbon's contribution characterised once on the first prototype | major |
| 027 | C20/C40/C60 change from 1 µF to 10 µF, keeping R20/R40/R60 at 10 kΩ, which moves the envelope AC-coupling corner from 15.9 Hz to 1.6 Hz; E-11 is restated as ≤ 2 Hz. At 15.9 Hz the coupling removed the speech envelope it exists to pass. **This ECO is implemented: `design.py` fits 10 µF at C20, C40 and C60 today, the corner is 1.6 Hz into 10 kΩ, and E-11 is met as fitted.** The 1 µF and its 15.9 Hz are the superseded Rev A values and are named nowhere else | major |

---

## 10. Adversarial review of package v2

Every file was attacked again, this time with the netlist and the geometry available to check
prose against, and then a cross-document audit compared all seventeen documents with each
other and with `design.py`. The ECOs above are what the attack found in the design. What
follows is what it found in the package as a whole, and what remains open.

| # | Finding | Severity | Action |
|---|---|---|---|
| 1 | **CLOSED, and not the way it was expected to close.** The routing was machine-generated and unreviewed; a layout engineer read it between 3 and 5 September 2026, **declined the paid review and advised a redesign from the schematic**. Six of his seven findings are rules the DRC did not have; regraded under them the same geometry shows **1 311 occurrences** (`kicad/EEG-CAR-01_RevB_regraded_ECO-EEG-032.txt`). **Rev B is withdrawn from fabrication and Rev C is unrouted** | **was blocking; now superseded by ECO-EEG-030** | Placement and routing are bought. RFQ-EEG-002A is re-scoped to the review of the contractor's PLACEMENT, taken before routing is confirmed |
| 2 | The analogue module jumper is a ten-way ribbon with no interleaved grounds | major | 60 mm length limit; screened ribbon specified; E-04 restated to −80 dB at 50 Hz on the carrier (ECO-EEG-026); consolidation is the Phase 2 fix |
| 3 | LED_V is driven directly by GPIO48 | medium | 1 kΩ series with Vf 2.0 V gives (3.3 − 2.0)/1000 = **1.3 mA per site and 10.4 mA total**, within the ESP32-S3 pin rating; R78 allows a 47 Ω alternate; a buffer is the fallback |
| 4 | GPIO0 is used as the shift-register latch and is a strapping pin | low | it is pulled up on the DevKit and is an input at boot; the latch is an input to the 595, so a static high is harmless. The consequence is that J26 cannot enter download mode, so end-of-line flashing uses the DevKit's own USB-C port (section 5) |
| 5 | Dropping microSD to one bit halves the headroom | low | the frame payload is **50.7 kB/s at 1000 Hz** (1015 bytes every 20 ms) against about 2 MB/s available at 20 MHz; E-20's ≈70 kB/s and F-12's ≈64 kB/s are allowances that include STATUS and SIGNATURE frames and filesystem overhead, and are not changed |
| 6 | The ADS1299 modules' analogue rails are still commoned by default | medium | R92/R93 are separable links with a stated measurement to decide |
| 7 | **Corrected 2 September 2026. S-02 is met at 36.8 µA.** This row read "single-fault patient DC current is 53.2 µA against the 50 µA of RFQ S-02, so S-02 is not met" until ECO-EEG-024 was applied | **no longer blocking on the calculation; open for safety sign-off** | ECO-EEG-024 is applied in `design.py`: R1-R16 are **68 kΩ**, not 47 kΩ, and the single-fault DC figure falls from 53.2 µA to **36.8 µA** on bound A and 30.0 µA on bound B. E-10 moves to its **±1.0 dB** branch, which that requirement already states for exactly this case. Applying the fix the analysis pointed to is not the same as having it approved: **SR-01 is closed in the design and not signed off**, and the electrical safety reviewer owns the disposition. The arithmetic for both values is in RISK-EEG-011 section 4, **which has not yet been re-issued for 68 kΩ and still prints 53.2 µA as the live state** |
| 8 | **The charge thermistor of RFQ S-04 is not implemented and stays not implemented** | major, open hardware item | there is no NTC net in `design.py` and no thermistor way on J12 or J13. It is listed as open here and in RISK-EEG-011, and it is never described as met. The 45 °C charge inhibit itself is RFQ E-23, met by the charger module's own thermal regulation |
| 9 | **Corrected 2 September 2026. The contact-light bicolour phase driver is written**, so E-27 is met in the firmware. This row read "specified and not coded" until that date | closed in the code, **open until a unit exists** | `lights_task()` reads `LOFF_STATP` and `LOFF_STATN` and alternates a green and a red phase; the alternation quantises to the FreeRTOS tick at about **250 Hz**, above E-27's 100 Hz. **TST-EEG-004 step T11 has not been run**, because no unit exists and no light has ever been driven, and a site that has lost contact currently shows amber rather than red because only `LOFF_SENSP` is enabled (section 5) |
| 10 | The isolator module's host connector is USB-B where RFQ E-24 asks for USB-C | **live non-conformance** | the interim answer is a short USB-B-to-USB-C panel pigtail, WH-09, until an isolator module with a USB-C host connector is qualified. It is not settled |
| 11 | J15–J17 have no confirmed part | open | `design.py` names Stäubli SLB1,5-F as a class, not a bought part. A touch-proof 1.5 mm socket with a PCB-mount signal pin and two 1.5 mm retention posts must be sourced and first-articled before Phase 2; AVL-EEG-017 carries a 12-week lead-time risk against it |
| 12 | The carrier draws a calculated 288 mA worst case from the DevKit's on-board 3.3 V regulator | medium, **not solved** | that is inside its rating but dissipates about 0.5 W inside a closed pod. TST-EEG-004 step T3 measures it and reports the case temperature; above 85 °C, a 3.3 V regulator on the carrier fed from V5V is **an ECO against Rev C of the board** |
| 13 | The comparator re-referencing of ECO-EEG-023 changes the only analogue-to-digital crossing on the board | major | it is called out explicitly for the safety and layout reviewer rather than buried in the ECO register |
| 14 | **Series 68 kΩ with 10 nF gives a 234 Hz corner and 0.75 dB of loss at 100 Hz.** Corrected 2 September 2026: this row read "47 kΩ … 339 Hz … 0.36 dB" until ECO-EEG-024 was applied | low | inside the **±1.0 dB branch of E-10**, which the requirement states for exactly the 68 kΩ case; the ±0.5 dB branch described the 47 kΩ that is no longer fitted. 4.7 nF is still the approved alternate |
| 15 | Nothing in this package has been manufactured or measured | **stated everywhere** | Phase 1 |
| 16 | No safety engineer has reviewed any of it | **blocking for use on a head** | RISK-EEG-011 is the pack the reviewer is given; the review gates Phase 2 |
| 17 | USB VID/PID are placeholders | medium, blocks the fleet not the prototypes | pid.codes application before Phase 2 |
| 18 | Module header geometry is still not fixed by anything | accepted | removed from the critical path by the jumper architecture; the cost is stated in 2.1 |
| 19 | The end-to-end production simulation (SIM-EEG-018 Rev A) is a simulation, not a build | **stated** | `tools/simulate_production.py`, re-run on 2 September 2026 after the design and firmware changes of that day, prints **193 checks passed, 0 failed and 6 known open items**, which is what SIM-EEG-018 Rev A carries. The six are: the linked image reports **static IRAM full with one byte free**; the v1 HM-01 mesh is two disconnected bodies; **no human layout engineer has reviewed the routing**; **E-27 has never been seen to light** (the driver exists, no unit does); the two board-current figures cannot both be right; and **SR-01 is closed in the design and not yet signed off**. Corrected 2 September 2026: this row read "171 passed, 0 failed and 5 known open items", and its five named E-11's low-pass half and E-27's missing driver, both of which are now met, and S-02's single-fault current, which is now met at 36.8 µA. It checks arithmetic, data integrity and procedure completeness; it cannot find what only a real build finds |
| 20 | Seventeen documents written in parallel from one fact base disagreed in sixty places | major, documentation | every disagreement was ruled on, the rulings that change the design are ECO-EEG-019 to ECO-EEG-027, and the structural rule from here is one table with one home and a cross-reference everywhere else |

---

## 11. The honest line

A manufacturer can quote, today, and can build most of it, today: the assembly, the printed
parts, the harness, the provisioning and the production test of TST-EEG-004 Rev C. The bare
board **cannot be fabricated yet**, and the reason has changed: the board now meets all three
conditions of the ECO-EEG-016 section 3 gate -- zero DRC violations, every net one connected
copper island, both inner planes continuous under the analogue zone. **That was met and it was
not enough.** A layout engineer read the routing, declined the review and advised a redesign,
and **Rev B is withdrawn from fabrication** (ECO-EEG-030). Rev C is unrouted and its layout is
bought. **Nobody orders boards from any of it.**

What a manufacturer still cannot do at all is ship a unit for use on a participant, because
the firmware stubs must be completed, RFQ S-04's thermistor does not exist, and
the safety review has not been passed. **Corrected 2 September 2026:** this sentence also
carried "RFQ S-02 is not met at the fitted 47 kΩ". ECO-EEG-024 is applied, R1-R16 are 68 kΩ,
S-02 is met at 36.8 µA on the calculation -- and the safety review that has to accept that
calculation still has not started, which is why the sentence still ends where it does. Those are the programme's tasks, not the
manufacturer's, and RFQ-EEG-001 Rev E says so.

No hardware in this package has been built: no board has been fabricated, nothing has been
manufactured, and nothing has been measured. **Corrected 2 September 2026:** this paragraph
began "Nothing in this package has been built", and the firmware is now an exception -- it is
built, and it has booted in an emulator, and it has never run on silicon (section 5).
**No safety engineer has reviewed this design.** Every
performance figure in it is calculated, and each one is labelled as calculated where it
appears. The first thing Phase 1 does is find out which of them are wrong.

---

## Annex A -- Package index and precedence

Precedence, highest first:

1. **DSN-EEG-003** -- this document
2. **RFQ-EEG-001** -- requirements and acceptance
3. **ICD-EEG-006** -- module interfaces
4. **SCH-EEG-005** -- schematic set
5. **DSN-EEG-002** -- helmet design and assembly
6. **PARTS-EEG-019** -- part identifier register
7. **RUL-EEG-021** -- rulings register
8. `EEG_kit_BOM_for_bidders_RevC.xlsx` -- kit BOM

**DSN-EEG-002 Rev E, at 5 in that list, has not been re-issued** since package v2.1 and the
shipped file is byte-identical; ECO-EEG-016 section 1.1 carries it as "released, not reissued
in this round". It still governs the helmet, but three of its sections are superseded and a
reader must not work from them. **Section 7** says a charged spare cell travels in the case and
describes the battery hatch as interlocked to the session state: no spare cell travels
(REG-EEG-012 Rev B section 3.1, RISK-EEG-011 Rev B section 6.1) and there is no hatch interlock
in this design and none may be claimed (REG-EEG-012 Rev B section 3.4). **Section 10**'s
`HM-07` / `HM-08` part numbering is superseded by PARTS-EEG-019 Rev B sections 3.1 and 3.2 --
HM-08 is the battery hatch, HM-10 the keyed cell carrier and HM-07A/B/C the boom arm.
**Section 11**'s travel-case figure draws the withdrawn two-layer foam and is superseded by the
CASE-00 Rev C schedule of PKG-EEG-015 section 2.2, which section 4 above follows. Its
section 13, the "layout rules that are requirements, not preferences" this document cites
throughout, is not affected. The re-issue is open document work under ECO-EEG-016, not a
decision still to be taken.

**Two documents joined the register on 1 September 2026 and are controlled.**

| Document | What it is | How to use it |
|---|---|---|
| **RUL-EEG-021** | The register of the answers the two cross-document audits of 1 September 2026 made, each made once so that every document could be corrected against it. It began as an internal worksheet and is now a controlled document because released documents cite it | Cite it as **RUL-EEG-021** with a section letter, for example RUL-EEG-021 section A for the geometry rulings and section B for the instrument rulings. It ranks below this document and RFQ-EEG-001: where a ruling has been absorbed into a higher document, that document governs, and where a ruling and `tools/design.py` disagree, `design.py` governs |
| **SIM-EEG-018** | The end-to-end production simulation record: **193 checks passed, 0 failed, 6 known open items**, as `tools/simulate_production.py` printed it on 2 September 2026 after that day's design and firmware changes -- static IRAM full with one byte free, the v1 HM-01 mesh being two disconnected bodies, the unreviewed routing, E-27 never having been seen to light, the two irreconcilable board-current figures, and SR-01 closed in the design and not yet signed off. Corrected 2 September 2026: this row read "171 passed, 0 failed, 5 open", whose list named E-11's low-pass half, E-27's missing driver and S-02's single-fault current, all three of which are now met | It is a record, not a specification, so it carries no precedence. It is evidence that the procedures and the arithmetic hang together, and it is not evidence that anything has been built |

**The current revision letter of every controlled document, and the list of which documents
are controlled at all, is in the register at ECO-EEG-016 section 1.** Revision letters are not
restated here, because a second list is a second thing to keep in step.

Where a number appears in a document and in `tools/design.py`, **`design.py` governs**, and
the document is corrected at the next revision. `tools/emit_all.py` regenerates every
fabrication file from it in one pass, so the package cannot drift.

Each of the following has exactly one home, and every other document cites it rather than
copying it.

| What | Its one home |
|---|---|
| The bare-board specification | section 3.2 here |
| The zoning rule, the star-point rule and the isolation keep-out | section 3.3 here |
| The routing result and the release state of the fabrication data | section 3.4 here, transcribed from `kicad/EEG-CAR-01_RevB_DRC_report.txt`, which is the authority |
| The "layout rules that are requirements, not preferences" | **DSN-EEG-002 section 13**. This document has no section 13 |
| The module-to-connector table and the GPIO map | ICD-EEG-006 sections 1 and 5 |
| The ECO register | ECO-EEG-016 section 2 |
| The series-resistor noise-and-flatness arithmetic, for both the 47 kΩ that was fitted and the **68 kΩ of ECO-EEG-024 that is fitted now** | RISK-EEG-011 section 4, which has not been re-issued since ECO-EEG-024 was applied and still presents 47 kΩ / 53.2 µA as the live state |
| The test step numbers, T00 to T29 | TST-EEG-004 Rev C |
| The test fixture table, FIX-01 to FIX-04 and their letters | TST-EEG-004 Rev C section 6.1 |
| The public-key fingerprint definition | FW-EEG-001 section 7 |
| The serial-number format `TIOV-B-nnnn` | PKG-EEG-015 section 5 |
| The lithium-shipping procedure | PKG-EEG-015 section 7, with REG-EEG-012 section 3 stating only the obligation |
| The rulings of the two cross-document audits | RUL-EEG-021 |

## Annex B -- Standard reply to the nine respondents

> **Subject:** RFQ -- EEG field kit -- routed four-layer production package now available (Gerbers, drill, CPL, schematic, test spec)
>
> Dear {{ organization }} team,
>
> When we last wrote, our package was complete except for the routing, and we said so. It is
> now routed. Attached is the full production data set: Gerber X2 and Excellon drill files, an
> IPC-D-356A netlist for bare-board test, a BOM with manufacturer part numbers, separate SMT
> and through-hole pick-and-place files, fabrication and assembly drawings, an eight-sheet
> schematic, the firmware with its build system and provisioning script, and a standalone
> production-test specification with its fixtures designed.
>
> Two things changed while we did the routing, and they change what you are quoting. The
> carrier is now **150.0 × 130.0 mm**, not 130 × 124 mm, and it is a **four-layer** board --
> signal, reference plane, reference plane, signal -- rather than two. We had asserted that two
> layers would be enough. Doing the layout showed that they are not: on two layers the bottom
> side has to be both the reference plane and the second routing surface, and a sixteen-channel
> EEG front end needs a continuous reference under every analogue trace. Through vias only,
> 0.60 mm pad on a 0.30 mm hole, 1.60 mm finished, no blind or buried vias.
>
> Regenerating the package from a single machine-readable source also found fourteen defects in
> the previous revision, four of which would have made the board unbuildable, and a
> cross-document audit found sixty more disagreements between the documents. They are listed in
> DSN-EEG-003 Rev D section 9. We would rather tell you that than have you find them.
>
> Two things we are asking for. First, if you have a layout desk: RFQ-EEG-002A is now a
> **review** of the supplied routing rather than the routing itself -- read it against the rules
> in section 3.3, correct what is wrong and sign it off. The DRC now reports zero violations
> and all 145 nets connected. **That routing has since been read by a layout engineer, who
> declined the review and advised a redesign, and Rev B is withdrawn from fabrication**
> (ECO-EEG-030). Rev C is unrouted and its placement and routing are bought. **There is no
> fabrication data to quote from**, and we say so here rather than letting you find it.
> Second: RFQ-EEG-002B, fabrication and assembly at 2, 10, 25 and 50 units, module procurement
> or consignment, MJF printing, harness assembly, provisioning and test.
>
> The design files are and remain CC BY-SA 4.0, and we ask that any file you generate from them
> comes back to us under the same licence. The safety requirements of RFQ section 8 are
> unchanged; no certification is requested. Nothing in the package has been built and no safety
> engineer has reviewed it, which is why no unit will go on a person before that review.
>
> With thanks,
>
> Stephane van der Aa, Founder, TI One Voice -- one.witysk.org -- stephane@stepvda.com -- +32 493 70 16 01
>
> Attachments: `EEG_field_kit_package_v2.3.zip` (complete), or on request the fabrication subset
> `EEG-CAR-01_RevB_gerber_X2.zip` with `README_layer_map_and_checksums.txt`.

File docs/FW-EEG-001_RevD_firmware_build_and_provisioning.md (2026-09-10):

# FIRMWARE BUILD AND END-OF-LINE PROVISIONING

**Document:** FW-EEG-001  **Revision:** D  **Date:** 2026-09-01
**Issued by:** TI One Voice research programme (one.witysk.org), Brussels, Belgium
**Licence:** CC BY-SA 4.0 for this document; the firmware source is MIT
**Governing documents:** DSN-EEG-003 Rev D, then RFQ-EEG-001 Rev E. Where this
document and design.py disagree, design.py governs.

**Revision note (Rev C):** carries the layout findings -- the carrier is now 150.0 x 130.0 mm
and four layers -- and **rules** the ring-buffer depth to a 6 MiB ring, 126 s at 1000 Hz,
against the relaxed F-06 (ECO-EEG-025). That was a ruling, not a report of work done: when
Rev C was issued `main.c` still asked for 12 MiB, which was FW-D13 and open. The source has
since been changed and FW-D13 is closed -- see the correction note below. It corrects the
frame bandwidth to 50.7 kB/s, the end-of-line flashing route to the DevKitC-1's own UART
port, the E-28 position, the eFuse phasing and the contact-light driver status. The findings
of the second cross-document audit of 1 September 2026 that name this document -- the
layout-rules citation in section 3.1, the ring-buffer arithmetic in section 5.8, and the
microSD file layout, which this document now owns in section 5.9 -- are closed in this
issue. The revision letter does not move: these are corrections within one release, not a
new one.

**Correction note, 2 September 2026.** The firmware source was changed on 2 September and
this document is re-synchronised against it here. An independent review found that Rev C
described the *v1* source rather than the shipped one, and that matters more than ordinary
staleness: a specification is the contract a builder follows, and as issued this document
told them to re-introduce defects the source no longer had. What changed, and where this
document changed with it:

* `firmware/main/drivers.h` is **new**. `main.c` had been calling seven functions that
  `drivers.c` defines with no declaration in scope. An implicit declaration is an error in
  C99 and later, and ESP-IDF compiles with `-Werror=implicit-function-declaration`, so the
  project could not have been built as shipped; worse, where a compiler accepts it the
  return type is assumed to be `int`, which would have truncated `sd_free_mb()`'s
  `uint32_t` and misread the pointer returns with no diagnostic at all. Section 1.2.
* `main.c` now includes `board_pins.h`, `esp_attr.h` and `drivers.h`. **FW-D12 and FW-D13
  are closed in the source**, not merely ruled: the Rev A pin block is gone and
  `RING_BYTES` is 6 MiB at `main.c:101`.
* **FW-D14 is fixed.** `rx_poll()` strips the ten-byte frame header and checks the protocol
  version and the frame type before dispatch. It had been passing the whole frame, so
  `handle_command()` read header byte 0 -- the protocol version -- as the opcode; since
  `PROTO_VERSION` is 1 and `CMD_START_SESSION` is `0x01`, every command the browser tool
  sent started a recording session. Sections 1.1 and 6.1.
* The CMD_ACK payload is reshaped to section 6.2 exactly, in `ack_emit()`. Section 6.2 also
  records the one path that does **not** yet use it -- provisioning, now FW-D20.
* `CMD_IDENTIFY` sets `CAP_CODEC`, which nothing had ever set, so a working codec always
  read as absent; and it separates `CAP_ATECC` (the part is fitted and answering) from
  `CAP_PROVISIONED` (its configuration zone is locked), which had been conflated, so an
  unprovisioned board coming off the line reported no secure element at all. Section 6.3.
* Section 6.3's opcode table assigned `0x0F` to FW_UPDATE_END, colliding with the
  `CMD_IDENTIFY` that `main.c` and TOOL-EEG-022 have used since 1 September, and had no
  row at all for `0x10` `CMD_LOOPBACK`. The table now carries both commands and
  FW_UPDATE_END has moved to `0x18`.
* `webtest/tests/interop/` is **new**: it compiles the real `main.c` against small ESP-IDF
  stubs on a development host and drives it with the real browser-tool protocol module.
  Section 8. This was the first time any of this firmware had been compiled or executed at
  all, and it was not a build against ESP-IDF and not a run on hardware. **Superseded the
  same day** -- see the build note immediately below.

**Build note, 2 September 2026.** The firmware was **built** later the same day, against a
real ESP-IDF installation, and then **run under QEMU**. Both are new facts and both are
narrower than they sound; the whole of this document is re-synchronised against them here,
because a specification that still says "never compiled" after the compile is a document a
reader has to second-guess.

* The build is **ESP-IDF v5.2.5**, target `esp32s3`, from `sdkconfig.defaults` plus
  `sdkconfig.phase1`. Section 2.1 pinned **v5.2.2** and is corrected. The four release
  images and a manifest of their SHA-256 are in `firmware/release/`; section 9 carries the
  figures.
* Getting there took five corrections to the **project**, not to the protocol, and each is
  recorded in the file it was made in: `esp_driver_i2c` does not exist at IDF 5.2 and the
  component list would not configure; `CONFIG_BOOTLOADER_APP_ANTI_ROLLBACK=y` had been
  appended to `sdkconfig.phase1` below the deliberate `=n`, where a later duplicate silently
  wins, and ESP-IDF refuses anti-rollback on a table carrying a `factory` partition, so the
  build stopped; `CONFIG_TINYUSB_VENDOR_ENABLED` is not an option name that exists in
  `esp_tinyusb` 1.4.x, so the vendor interface this device is built around was silently
  absent -- the real key is `CONFIG_TINYUSB_VENDOR_COUNT`; and three descriptor callbacks
  were defined here **and** in `esp_tinyusb`, which is FW-D02, and the link failed until the
  three were deleted and the component left to own them; and the five `sdkconfig` lines this
  document had listed as "must be added before the first build" were still not added.
  Sections 2.2 and 2.4.
* **FW-D02, FW-D03, FW-D11 and FW-D16 are closed, and FW-D20 is closed.** The
  `_Static_assert` on the MS OS 2.0 descriptor length has now been evaluated against
  resolved macros and held; the bicolour contact-light phase driver is written, so **E-27 is
  met in the source** and the FW-D16 row is retired; and `handle_provision()` now answers
  through `ack_emit()`, so the provisioning family is the section 6.2 acknowledgement.
  Sections 1.3, 3.2 and 6.2.
* Two opcodes were added: **`0x4A` CMD_READ_CALIBRATION** and **`0x4B`
  CMD_ATECC_WRITE_CONFIG**. Section 6.3's table did not carry them and now does.
* Section 7.3's table said it was `provision.py`'s step list. It was not, and the divergence
  was not cosmetic: the script writes and locks the ATECC configuration zone **before**
  GenKey, because a factory-fresh part will not generate a key into an unconfigured slot.
  That section is rewritten from the script.
* The QEMU run is in `firmware/release/qemu_boot.log`. **It is an emulator, not a unit**,
  and section 8.2 states exactly what it does and does not prove.
* The build produced two memory figures and one of them is a finding. The image is
  **405,245 bytes** in a 3 MB slot, which is ample. **Static IRAM is 16,383 of 16,384 bytes
  used -- one byte free**, which is a cliff and not a margin, and taking two unused ISRs out
  of IRAM did not move it by a byte. Section 9 records both and section 10 item 17 carries
  the open one.
* Every line count and line-number citation in sections 1.1, 1.2 and 1.3 was stale by up to
  130 lines and is re-counted; the interop harness reports **57 checks**, not the 32 section
  8.1 quoted.

The revision letter does not move: nothing here is a new release. Two things a reader tracks
**do** change, and they are called out rather than buried. The ESP-IDF pin moves from
**v5.2.2 to v5.2.5**, which is the version that produced the shipped images, and anyone
reproducing the build must use it. And **E-27 moves from not met to met in the source**,
because the phase driver it was waiting on is written -- met in the source is not signed
off, and TST-EEG-004 T11 still needs a unit and a colorimeter. No pin, no part and no
quotable quantity changes.

## Why this document exists

Package v1 shipped one file, `firmware/main.c`, and nothing around it. There was no
project, no configuration, no partition table, no pin map that matched the board, no
provisioning script and no host tool -- yet RFQ-EEG-001 section 1.1 asks a manufacturer to
price "firmware loading and provisioning at the end of the line (we supply the firmware
image and the provisioning script)", and TST-EEG-004 makes running that script a test step.
This document specifies everything that was missing, states exactly what the source does
and does not do today, and defines the byte-level contract that the firmware, the
manufacturer's test station and the programme's browser session runner must all agree on.

*Corrected 2026-09-02.* This paragraph read "**Nothing in this package has been built, and
no safety engineer has reviewed this design.** Nothing here has been compiled or run on
hardware." Half of that is no longer true and the half that is withdrawn is withdrawn
here rather than deleted: the firmware **was** compiled, against ESP-IDF v5.2.5, on
2 September 2026, and the images are in `firmware/release/`. What still stands, unchanged
and in full:

**No safety engineer has reviewed this design. No board has been fabricated and no unit
exists.** The firmware has run only under QEMU, whose `esp32s3` machine emulates none of
this instrument's peripherals (section 8.2). Every number marked *calculated* is still
calculated, and every register value, daisy order and SPI timing in this document is still
an assumption that no silicon has answered.

---

## 1. What exists and what is stubbed

The reference source is no longer one file. It is `firmware/main/main.c` (832 lines),
`firmware/main/drivers.c` (580 lines) and `firmware/main/drivers.h` (77 lines), over the
generated `firmware/main/board_pins.h` (74 lines); counted with `wc -l` on the shipped files
at 2 September 2026. *Corrected 2026-09-02: this paragraph said 705, 476 and 69, which were
the counts before the phase driver, the two new provisioning opcodes and the acknowledgement
rework landed.* `main.c` was 362 lines in v1, and the growth is the provisioning handler of
section 7, the acknowledgement of section 6.2, the contact-light phase driver of section
3.2, the two connectivity commands of TOOL-EEG-022 and the receive-path fix.

**It builds.** *Corrected 2026-09-02: this paragraph used to say the source had "never been
built against a real ESP-IDF installation".* It has been, once, on 2 September 2026:
ESP-IDF **v5.2.5**, target `esp32s3`, `sdkconfig.defaults` + `sdkconfig.phase1`, clean at
ESP-IDF's default `-Wall -Werror=all`. The four images and their SHA-256 are in
`firmware/release/` and section 9 carries the figures. That closes the *build* half of the
FW-D01 exit criterion and it retires nothing else.

Read the rest of the claim narrowly, because three different things have now happened to
this source and they prove three different amounts:

| What ran | What it proves | What it does not |
|---|---|---|
| `sh webtest/tests/interop/run.sh` -- `main.c` compiled on a development host against small ESP-IDF stubs and driven by the real browser-tool protocol module: **57 checks, all passing** | the firmware and the host tool agree about framing, the CRC, the header, the opcodes, the acknowledgement layout, the S-01 interlock and the `0x4A`/`0x4B` split | nothing about ESP-IDF, TinyUSB, the descriptors or any peripheral: the stubs expand the descriptor macros to placeholders |
| `idf.py build` against **ESP-IDF v5.2.5** | every ESP-IDF header, Kconfig option and TinyUSB macro this file names resolves; the `_Static_assert` on the 10-byte frame header and the one on the MS OS 2.0 descriptor length both held; the image links and fits | that any of it is *right*. A register value that assembles is not a register value the ADS1299 accepts |
| `qemu-system-xtensa -M esp32s3` -- one full boot, `firmware/release/qemu_boot.log` | the image boots, the bootloader reads **this** partition table, the app loads from the `factory` slot, `app_main()` runs, and the microSD, codec and ring-buffer paths behave as written | every peripheral. QEMU's `esp32s3` has no octal PSRAM, no microSD, no ES8388 and no ADS1299. Section 8.2 |

It has still **never run on hardware**, so the daisy order, the SPI timing, every register
value and the whole analogue front end remain assumptions. The two C++ range-based `for`
loops that made the v1 file a syntax error in C are gone (FW-D01).

The following inventory is what a reader will find in the file today.

### 1.1 Implemented in full

Line numbers are `main.c` at 2 September 2026, **re-counted after the build**. *Corrected
2026-09-02: every line number in this table was stale, by up to 130 lines at the foot of the
file.*

| Function | Lines | What it does | Confidence |
|---|---|---|---|
| `crc32()` | 115-119 | IEEE 802.3 reflected CRC-32, polynomial `0xEDB88320`, init `0xFFFFFFFF`, final inversion. Matches Python `binascii.crc32` | High -- byte-checkable offline, and checked against the host implementation by the interop harness |
| `cobs_encode()` | 121-128 | Standard COBS with the trailing `0x00` delimiter written by the encoder | High -- decoded by the browser tool in the interop harness |
| `frame_hdr_put()` | 147-159 | Serialises the ten-byte header field by field, with a `_Static_assert` on the length (FW-D19) | High -- the harness parses the result with the host decoder, and the assert held in the ESP-IDF build |
| `frame_emit()` | 167-184 | Builds header, appends payload, appends CRC, COBS-encodes, writes to CDC, vendor, ring buffer and SD | Structurally complete, **not thread-safe** (see FW-D04) |
| `ads_cmd()`, `ads_wreg_all()`, `ads_set_rate()` | 187-198 | Single-byte opcodes and daisy-chain register writes | Register values plausible, never verified against silicon |
| `ads_init()` | 199-224 | SPI bus, reset sequence, CONFIG1/2/3, per-channel gain, lead-off, MISC1, RDATAC | Compiles and links; never run against a converter, in QEMU or anywhere else |
| `drdy_isr()` | 237-247 | Increments `g_sample_index`, latches the envelope-comparator level and records its rising edge (FW-D08), notifies the sample task. **The only place the counter moves** (E-19) | Correct in principle |
| `aux_bits()` | 248-257 | Builds six of the sixteen auxiliary bits | Incomplete, see section 5.3 |
| `sample_task()` | 258-282 | 54-byte daisy read, de-interleaves the two devices, packs 50-byte sample records, emits one frame every 20 ms | Never run; daisy order is an assumption |
| `lights_write()` | 285-288 | Shifts eight bits into the 74HC595 and latches | Never run |
| `lights_phase()`, `lights_task()` | 325-360 | **The bicolour phase driver (E-27).** Phase A lights the wanted sites green with `LED_V` high, phase B lights them red with `LED_V` low, a site in both is amber; the masks come from the converter's positive-side lead-off comparator read at **two thresholds** -- trips neither is green, the sensitive one only is amber, both is red (FW-D17). Dark while recording, and `LED_V` is returned to an **input** rather than driven low, which is dark by construction | **Written, on 2 September 2026 -- FW-D16 is closed and E-27 is met in the source.** Never run. The alternation quantises to the FreeRTOS tick: nominal `LIGHT_PHASE_HZ` 240, actual about **250 Hz** -- section 3.2 |
| `ack_emit()` | 430-439 | The section 6.2 acknowledgement: opcode echoed, reserved zero, status, result length, result | High -- decoded by the browser tool's own `parseAck()` in the harness |
| `handle_provision()` | 441-561 | The **thirteen** `0x40`-`0x4B` and `0x4F` provisioning opcodes of section 7, including `0x4A` CMD_READ_CALIBRATION and `0x4B` CMD_ATECC_WRITE_CONFIG | Never run against an ATECC608B. Its acknowledgement **is** the section 6.2 one as of 2 September -- FW-D20 closed |
| `handle_command()` | 563-658 | Dispatches eleven general opcodes -- `0x01`-`0x05`, `0x08`-`0x0B`, `0x0F`, `0x10` -- and routes `0x40`-`0x4F` to `handle_provision()` | Five declared opcodes still fall to the unknown-opcode arm: FW-D10 |
| `timing_selftest()` | 664-670 | 40 tone bursts, insertion sort, median and p95 | The two functions it calls now exist in `drivers.c`; neither has driven a codec |
| USB descriptor tables, `tud_descriptor_bos_cb()` | 673-722 | Device, configuration, string and BOS descriptors. *Corrected 2026-09-02:* there are **not** four `tud_descriptor_*_cb` callbacks here any more. `esp_tinyusb` owns the device, configuration and string callbacks and is handed those three as **data** through `tinyusb_config_t`; defining them here as well is FW-D02 and it failed the link with three "multiple definition" errors. Only `tud_descriptor_bos_cb()` stays, because `esp_tinyusb` 1.4.x defines none and `tinyusb_config_t` has no field for one | Macro names now **resolved** against the pinned `esp_tinyusb` by the real build, and `MS_OS_20_DESC_LEN` asserted. Never enumerated by a host |
| `tud_vendor_control_xfer_cb()` | 723-734 | Serves the WebUSB URL and the MS OS 2.0 descriptor | Never run |
| `rx_poll()` | 736-763 | One pass of the receive loop: COBS-decode, check the CRC, **skip the ten-byte header and check the version and the frame type**, then dispatch (FW-D14). Factored out of `rx_task()` so a host harness can drive the real path rather than a copy of it | Exercised end to end by the interop harness |
| `rx_task()` | 765-770 | Calls `rx_poll()`, and yields for 2 ms when it read nothing | Never run |
| `status_task()` | 773-778 | One STATUS frame per second | Payload is **still** 12 bytes carrying four of the eight items F-09 names, with link type at offset 8 where section 5.4 puts uptime (FW-D09, open) |
| `app_main()` | 780-825 | GPIO setup, `drv_init_all()`, serial read, ring buffer with an explicit abort if PSRAM will not give it, TinyUSB install, ADS init, four tasks | Runs to completion in QEMU as far as the ring-buffer allocation, which QEMU cannot satisfy and which aborts with the named diagnostic FW-D13 added. Never run on a target |

### 1.2 The drivers are written now, and none of them has run

At v2.1 these six symbols were declared `extern` **inside function bodies** and defined
nowhere in the package. They are now declared in `firmware/main/drivers.h` and defined in
`firmware/main/drivers.c`, which is in `SRCS` (section 2.2). Writing a driver and proving
one are different claims and only the first has happened: not one of these has addressed a
real peripheral, so every I2C address, register write and timeout below is still an
assumption, and the test steps in the last column still gate on hardware.

*Line numbers corrected 2026-09-02.*

| Symbol | Defined at | Driver | Called from | Blocks |
|---|---|---|---|---|
| `void sd_append(const uint8_t *, size_t)` | `drivers.c:163` | SDMMC, one-bit | `frame_emit()`, every frame | T14 |
| `uint32_t sd_free_mb(void)` | `drivers.c:175` | SDMMC | `status_task()`, `CMD_IDENTIFY` | T14, F-09 |
| `void atecc_serial_into(char *, size_t)` | `drivers.c:288` | ATECC608B I2C | `handle_provision()` at `0x43` | T5b, T6, F-04 |
| `uint8_t battery_percent(void)` | `drivers.c:107` | MAX17048 I2C | `status_task()` | F-09, E-22 |
| `void codec_play_tone_at(uint32_t)` | `drivers.c:234` | ES8388 I2S | `timing_selftest()` | T12, T13, T17 |
| `int envelope_onset_after(uint32_t, int)` | `drivers.c:250` | signal | `timing_selftest()` | T12, T13 |

`drivers.c` also defines `unit_serial_into()`, the `drv_atecc_*` and `drv_nvs_*` groups
section 7 needs -- including `drv_atecc_write_config()` at `drivers.c:431` and
`drv_nvs_get_blob()` at `drivers.c:552`, both added on 2 September for the two new
provisioning opcodes -- and `drv_codec_ready()` and `drv_atecc_present()`, which are what
`CMD_IDENTIFY` reports as `CAP_CODEC` and `CAP_ATECC`.

**The QEMU run exercised three of these paths and answered a question about all of them.**
`drv_sd_init()` timed out, `drv_codec_init()` timed out on ES8388 register 0x00, and both
logged the failure and continued rather than aborting, which is what they were written to
do. That is a bring-up behaviour test and nothing more: QEMU emulates neither part, so a
timeout is the only answer it could ever have given, and no I2C address, register write or
timeout below has yet been answered by a part.

`drivers.h` exists because it had to. `main.c` called seven of these functions with no
declaration in scope, which is an error in C99 and later and which ESP-IDF rejects at
`-Werror=implicit-function-declaration`; and where a compiler does accept an implicit
declaration it assumes a return type of `int`, so `sd_free_mb()`'s `uint32_t` and the
pointer returns would have been truncated or misread at runtime with no diagnostic. Include
it from both files, so the compiler checks the definitions against the prototypes the
callers use.

A seventh item is worse than a stub: the **block-signing task is not declared at all**. The
closing comment says SIGNATURE frames are "emitted as FT_SIGNATURE by the sd/signing task
(not shown)". Nothing emits them, so T16 -- the only place the study's integrity mechanism
is ever tested -- has no input. That is unchanged at 2 September: `drivers.c` contains no
SHA-256, no chained digest, no signing call and no such task, and F-08 is therefore
unimplemented rather than merely untested.

### 1.3 The bring-up defect register

These are the defects found by reading the file, and -- from 2 September 2026 -- by
building it. Each is a work item with an acceptance test. Anyone quoting firmware bring-up
should quote against this table, not against "complete the stubs". Twenty entries;
**fourteen are fixed or closed in the source and six are open**. *Corrected 2026-09-02:
this line read "nine are fixed and eleven are open". FW-D02, FW-D03, FW-D11, FW-D16 and
FW-D20 have closed since, four of them because the first real build forced them into the
open.*

A row marked FIXED means the source no longer has the defect. It does not mean the
acceptance test has been run: the acceptance column is the gate, and for most of these rows
that gate is a unit on a bench, which does not exist. **The build gate, however, is now
real** -- `idf.py build` against ESP-IDF v5.2.5 completes clean at ESP-IDF's default
`-Wall -Werror=all` -- so where a row's acceptance was "build once", that row is genuinely
retired and the column says so.

The six open rows are **FW-D04, FW-D05, FW-D06, FW-D07, FW-D09 and FW-D10**. Five of the
six are frame-integrity or protocol-completeness items and none of them is visible to a
compiler; the sixth, FW-D09, is a wire-format shortfall a host decodes wrongly in silence.

| ID | Defect | Violates | Fix | Acceptance |
|---|---|---|---|---|
| FW-D01 | C++ range-based `for` in `app_main()`, twice | compiles as C | **FIXED**: explicit arrays and an index loop, `main.c:783-793` | **MET 2026-09-02.** `idf.py build` against ESP-IDF v5.2.5 completes clean at ESP-IDF's default `-Wall -Werror=all`. A full `-Wextra -Werror` build has not been demonstrated and is not what ESP-IDF sets |
| FW-D02 | Descriptor callbacks defined **and** the same descriptors passed to `tinyusb_driver_install()` | link error | **FIXED 2026-09-02, and the predicted fix was the wrong one.** This row used to say "set `CONFIG_TINYUSB_DESC_CUSTOM=y` and keep the callbacks". Doing both is exactly the defect: with `CONFIG_TINYUSB_DESC_CUSTOM=y` the descriptors are supplied as **data** through `tinyusb_config_t` and `esp_tinyusb` owns the callbacks. The link failed with three "multiple definition" errors against `descriptors_control.c` until `tud_descriptor_device_cb()`, `tud_descriptor_configuration_cb()` and `tud_descriptor_string_cb()` were deleted from `main.c`. `tud_descriptor_bos_cb()` stays, because the component defines none | **Build gate MET** (the image links). T5 for enumeration |
| FW-D03 | The TinyUSB vendor class is not enabled, so `tud_vendor_*` has no backing interface | F-01 | **FIXED 2026-09-02, and the option name in this row was wrong.** `CONFIG_TINYUSB_VENDOR_ENABLED` **does not exist** in `esp_tinyusb` 1.4.x, and ESP-IDF does not fail on an unrecognised Kconfig key -- it warns and carries on. So the setting looked present, `CFG_TUD_VENDOR` stayed 0, `tusb.h` declared none of the `tud_vendor_*` functions, and the WebUSB half of F-01 would simply not have existed. It surfaced as "implicit declaration of function `tud_vendor_mounted`" the first time the file met a real compiler. The real key is **`CONFIG_TINYUSB_VENDOR_COUNT=1`**, now in both `sdkconfig.defaults` and `sdkconfig.phase1` | **Build gate MET.** T5 for enumeration |
| FW-D04 | One static `txbuf`/`cobsbuf` pair written by four callers at priorities 23, 10, 5 and 4 with no mutex | frame integrity | a recursive mutex around `frame_emit()`, or per-task encode buffers | T14, 30 min, zero bad CRC |
| FW-D05 | The overflow path drops the oldest frames and emits no GAP | F-07 "silent loss is not permitted" | emit FT_GAP per section 5.5 | T15 |
| FW-D06 | `CMD_RETRANSMIT` ignores its range and drains the ring destructively | F-06 | index the ring by sequence, copy without consuming | T15 complete recovery |
| FW-D07 | `g_seq++` from three tasks, non-atomic | frame ordering | increment under the FW-D04 mutex | T14 |
| FW-D08 | The comparator aux bit is sampled in the task, not latched in the DRDY ISR | E-12 sub-sample onset | **FIXED**: `drdy_isr()` latches the level and records the rising edge in `g_onset_sample`, and `aux_bits()` reports the latched value (`main.c:235-255`) | T12b |
| FW-D09 | STATUS carries battery, lead-off, SD free and link type only, in a 12-byte payload, and link type sits at offset 8 where section 5.4 puts uptime, so a host parsing per section 5.4 decodes it as part of uptime | F-09 (8 items) | the 24-byte, 10-field payload of section 5.4, which includes the ring depth T15 grades against (section 5.8) | T14, T21, T15 |
| FW-D10 | **Open, and unchanged by the build.** `CMD_SET_GAIN`, `CMD_IMPEDANCE`, `CMD_PLAY_AT`, `CMD_FW_UPDATE_BEGIN` and `CMD_PROVISION` are still declared in the enum (`main.c:363-369`) with no case arm, so all five reach the `default:` arm. The status they now return is `0x01`, unknown opcode -- **not** `0xFF` any more, and not the `0x0B` not-implemented that section 6.2 defines and that a host needs in order to tell a missing feature from a typo. Of the five, only `CMD_PROVISION` is answered elsewhere: provisioning has moved to the `0x40`-`0x4F` family, which `handle_provision()` implements in full, so `0x0E` should be deleted from the enum rather than written | F-10 | section 6; and return `0x0B`, not `0x01`, where the honest answer is "not implemented in this build" | T10, T11, T12, T17 |
| FW-D11 | `_Static_assert(sizeof(ms_os_20_desc) == 0xB2)` never checked against resolved macros | F-02 | **CLOSED 2026-09-02**: the assert (`main.c:705`) was evaluated in the ESP-IDF v5.2.5 build against the pinned `esp_tinyusb` and held, as did the ten-byte header assert at `main.c:160`. Every TinyUSB macro this file names now resolves. What that does **not** settle is whether Windows accepts the descriptor set | T5 on Windows 11 |
| FW-D12 | `main.c` carried the **Rev A** pin defines: `PIN_SR_DATA 35`, `PIN_SR_CLK 36`, `PIN_SR_LATCH 37`, which are the octal PSRAM bus, so a unit flashed with it would have torn down the memory the ring buffer lives in | ECO-EEG-009 | **FIXED**: the block is deleted and `main.c` includes the generated `board_pins.h`, which comes from `design.py`, so the firmware and the board cannot disagree | T11 |
| FW-D13 | `RING_BYTES` was 12 MiB; the -N16R8 carries 8 MiB of PSRAM in total, so the allocation returned NULL and the first DATA frame asserted inside `xRingbufferSend` | F-06 | **FIXED**: `RING_BYTES` is `6*1024*1024` at `main.c:101`, and `app_main()` now aborts with a named diagnostic if PSRAM will not give it. F-06 relaxed by ECO-EEG-025 -- section 5.8. **The diagnostic has been seen to work**: it is the last line of `firmware/release/qemu_boot.log`, because QEMU has no PSRAM at all to allocate from | T15 |
| FW-D14 | `rx_task()` treated the first decoded byte as the opcode; the host tool sends a full frame header first. The consequence was worse than non-interoperation: byte 0 is the protocol version, `PROTO_VERSION` is 1 and `CMD_START_SESSION` is `0x01`, so **every** command from the browser tool started a recording session, and the one command that appeared to work did so by that coincidence | interoperability | **FIXED on 2 September 2026**: `rx_poll()` dispatches from `out + FRAME_HDR_BYTES` and refuses any frame whose version is not `PROTO_VERSION` or whose type is not `FT_CMD` (`main.c:609-636`) | 32 of 32 in `webtest/tests/interop`; a provisioning dry run against hardware is still outstanding |
| ~~FW-D15~~ | *Closed at Rev C.* The header said "written against RFQ-EEG-001 Rev B" while the package shipped Rev E | traceability | done: this document is headed **RFQ-EEG-001 Rev E** and section 5 is written against it | closed |
| FW-D16 | The bicolour contact-light phase driver did not exist. `lights_write()` and `lights_task()` drove the 74HC595 on and off only; nothing alternated LED_V against the shift-register outputs, so no site could show red or amber | E-27, RFQ E-27's amber state | **FIXED 2026-09-02**: `lights_phase()` and `lights_task()` (`main.c:325-360`) drive LED_V (GPIO48) and Q0-Q7 in antiphase, and the three colours come from the converter's positive-side lead-off comparator read at **two thresholds** -- trips neither is green, the sensitive threshold only is amber, both is red (as corrected by FW-D17, below; as first written this used `LOFF_STATP & LOFF_STATN`, and red was unreachable). **E-27 is met in the source.** The alternation quantises to the 1 kHz FreeRTOS tick and runs at about **250 Hz**, not the nominal 240; the requirement is "above 100 Hz" and 250 Hz meets it. Section 3.2 | **T11.** The driver is written, so T11 is no longer blocked by its absence; it still needs a unit and a colorimeter, and it has never been run |
| FW-D17 | **`CMD_START_SESSION` armed a session without ever reading `PIN_VBUS_DET`.** Only the CHG_CE half of S-01 existed, so a unit tethered to a mains-powered charger would record | S-01 | **FIXED at Rev C**: the handler refuses first and returns ack status `0x05`, per section 6.1 | T21, and the interlock half of T3 |
| FW-D18 | `CMD_SET_RATE` issued WREG CONFIG1 while the converter was in RDATAC; the ADS1299 ignores register writes in that mode, so the rate silently did not change | E-02 | **FIXED**: START low, SDATAC, write CONFIG1, RDATAC, START high (`main.c:512-523`) | T2 at all three rates |
| FW-D19 | **The frame header was `memcpy`d onto the wire with `sizeof(frame_hdr_t)`, which is 12, not 10.** The struct is tail-padded to its 4-byte alignment, so two padding bytes sat between the header and the payload and every host parser written to section 5.1 -- including this package's own `verify_stream.py` -- misparsed every frame by two bytes | section 5.1 | **FIXED at Rev C**: the header is serialised field by field by `frame_hdr_put()`, with a `_Static_assert` on the 10-byte length. A wire format is a contract with other people's software and must never be a struct copy | T5b, and TOOL-EEG-022 step D4 |
| FW-D20 | The provisioning acknowledgements were not the section 6.2 acknowledgement. `handle_provision()` built `{opcode, status, result...}` and called `frame_emit()` directly, while `ack_emit()` and every other reply send `{opcode, reserved 0, status, result length, result...}`. `provision.py` reads the status at absolute frame offset 12, which is payload offset 2, so it read the first *result* byte as the status: on `0x48` READ_PROVISION_STATE that byte is the config-zone lock flag, so an **unlocked** unit reported 0 and looked like a success -- the one command whose whole job is to say whether provisioning happened answered "fine" for a blank part | section 6.2 | **FIXED 2026-09-02**: the whole `0x40`-`0x4F` family returns through `ack_emit()` (`main.c:561`), including the not-in-provisioning-mode refusal. Status codes are unchanged; only the envelope moved | T6. **The interop harness now covers the shape**: three of its 57 checks read a provisioning status at the section 6.2 offset, and one of them is a `0x02` bad-length refusal that would have decoded as something else under the old shape. A run against a real ATECC608B is still outstanding |

Exit criterion for the whole backlog: a clean build at `-Werror`, enumeration on Windows 11,
macOS and Ubuntu (T5), and T13 reporting median <= 1 and p95 <= 2 samples. *Corrected
2026-09-02: the first of those three is now met* -- the ESP-IDF v5.2.5 build is clean at
`-Wall -Werror=all`. **The other two are not, and they are the ones that need a unit.** The
host harness of section 8 is not that build and retires nothing; it is a guard against the
firmware and the host tool drifting apart again. The QEMU run of section 8.2 retires nothing
either: a boot on an emulator with none of this instrument's peripherals cannot grade a
single row above.

---

## 2. Build environment

### 2.1 Toolchain

*Corrected 2026-09-02.* This table pinned **v5.2.2**. The firmware was built with
**v5.2.5** -- the released images in `firmware/release/` and their `manifest.json` say so --
and a document that pins a version nobody used is a document a second builder will not
reproduce. The pin moves to the version that produced the shipped images. `v5.2.2` remains
inside the `>=5.2,<5.4` range `main/idf_component.yml` permits, so nothing about the
component resolution changes.

| Item | Value | Why it is pinned |
|---|---|---|
| ESP-IDF | **v5.2.5**, tag `v5.2.5`; `main/idf_component.yml` permits `>=5.2,<5.4` | The TinyUSB descriptor macros moved between releases (FW-D11), and this is the version the shipped images were built with |
| Managed component | `espressif/esp_tinyusb` `~1.4.2`, which **resolved to 1.4.5** in this build | Same reason. `firmware/dependencies.lock` records what actually resolved and is part of the release |
| Target | `esp32s3` | E-18, not substitutable |
| Host | Ubuntu 22.04 or Windows 11, Python 3.11 | The release container is Linux |
| Container | `espressif/idf:v5.2.5`, pinned by image digest | Reproducible build, section 9 |

**The build is not yet reproducible in the sense section 9 asks for.** The shipped images
were built on a developer machine, not in the pinned container, and the boot log records
the application version as `e91f9d58-dirty` -- a working tree with uncommitted changes.
Reproducing the SHA-256 list needs a clean tree and the container, and that has not been
done.

An unpinned build is a silent difference between units, and section 9 of RFQ-EEG-001 exists
because device identity must not become a confound in the study.

### 2.2 Repository layout

```
firmware/
  CMakeLists.txt            project eeg_field_kit, VERSION 0.2.0
  sdkconfig.defaults        the fleet configuration (section 2.4)
  sdkconfig.phase1          the Phase 1 overlay: no secure boot, no eFuses (section 2.4)
  sdkconfig.qemu            the emulator overlay -- NOT a configuration for any unit (8.2)
  partitions.csv            the flash layout (section 2.5)
  dependencies.lock         what the component manager actually resolved
  README.md                 status and the three commands
  main/
    CMakeLists.txt          idf_component_register(...)
    idf_component.yml       pinned dependencies
    board_pins.h            GENERATED from tools/design.py (section 3)
    drivers.h               the peripheral API main.c calls (section 1.2)
    drivers.c               the implementations of it (section 1.2)
    main.c                  the reference source
  tools/
    provision.py            end-of-line provisioning (section 7)
    verify_stream.py        host verification (section 8)
    provision_selftest.py   offline checks on provision.py, including opcode uniqueness
    atecc608b_config.py     generates the ATECC608B configuration-zone template
  release/                  the built images, their manifest, the size report and the
                            QEMU boot log (sections 8.2 and 9).  ADDED 2026-09-02
```

`build/` is a build directory, not a release artefact, and is not part of the package.

The firmware also has a test that is not under `firmware/`: `webtest/tests/interop/`
compiles `main.c` against ESP-IDF stubs and drives it with the browser tool's protocol
module. It lives next to the tool it proves agreement with, and section 8 describes it.

`tools/provision.py` and `tools/verify_stream.py` are the source-tree paths and are the
names this package uses. Other documents in the release call the same two programs by other
names; that divergence is recorded as an open item in section 10 and is not resolved here.

`main/CMakeLists.txt` as shipped:

```cmake
idf_component_register(
    SRCS "main.c" "drivers.c"
    INCLUDE_DIRS "."
    # `driver` and NOT `esp_driver_i2c`.  The I2C driver was split into its own component
    # at ESP-IDF 5.3; at 5.2, which idf_component.yml also allows, `esp_driver_i2c` does
    # not exist and the build stops at configure with "component could not be found".
    # `driver` provides I2C on both, so it is the requirement that spans the pinned range.
    REQUIRES driver esp_timer esp_psram sdmmc fatfs esp_partition app_update
             nvs_flash
    PRIV_REQUIRES esp_tinyusb
)
```

*Corrected 2026-09-02.* This block used to list `esp_driver_i2c` in `REQUIRES`. **That
component does not exist at ESP-IDF 5.2** -- the I2C driver was split out into its own
component at 5.3 -- and `idf_component.yml` permits `>=5.2,<5.4`, so the build stopped at
configure with "component could not be found". `driver` provides I2C on both, so it is the
requirement that spans the pinned range, and the line is now what is in the file.

The drivers came in as one `drivers.c` rather than the six files this section used to
predict, and `nvs_flash` came in with them. What is still to be added is `signing.c` -- the
block-signing task of section 1.2, which nothing implements -- and an I2S component with it
if the tone generator moves out of `drivers.c`.

### 2.3 Commands, and how a unit is put into download mode

```sh
. $IDF_PATH/export.sh              # ESP-IDF v5.2.5
idf.py set-target esp32s3
idf.py build                       # -> build/eeg_field_kit.bin
idf.py size                        # app size must stay under 3 MB (section 2.5)
```

These are the commands that produced `firmware/release/` on 2 September 2026. The
Phase 1 build -- which is what was actually run, and what the two prototypes take -- adds
the overlay:

```sh
idf.py -DSDKCONFIG_DEFAULTS="sdkconfig.defaults;sdkconfig.phase1" build
```

`idf.py size` reported a **405,245-byte** image against a 3 MB slot, and static IRAM at
**16,383 of 16,384 bytes used**. The second of those is an open item, not a pass; section 9
gives both figures and section 10 item 17 carries the IRAM one.

Bench and end-of-line flashing both go through the **DevKitC-1's own UART USB-C port**:

```sh
idf.py -p /dev/ttyUSB0 -b 921600 flash monitor
```

**That port is the only flashing route, and it is the route the production line uses.** The
DevKitC-1 carries the auto-reset circuit on the module itself -- the bridge's DTR and RTS
lines drive EN and IO0 -- so `esptool.py` puts the ESP32-S3 into download mode with no
fixture, no relays and no operator action. The module is reachable with the pod lid off
through the 31 x 61 mm opening in the MP-01 module plate, so the carrier does not have to be
removed to flash a unit.

**The carrier's J26 header is console and recovery only and cannot enter download mode.**
J26 carries 3V3, DGND, UART0 TX, UART0 RX, EN and one spare way netted `NC_GPIO0`. GPIO0 is
committed to LED_SR_LATCH at J7 position 14 (ECO-EEG-009) and does not reach J26, so no
relay sequence on J26 can assert IO0. Any procedure that describes flashing through J26 with
a GPIO0/EN relay sequence is wrong. Console output is UART0 on GPIO43/44, brought to J26,
because TinyUSB owns the native USB peripheral on GPIO19/20.

RFQ-EEG-001 Rev E E-28 asks for TP1-TP18 on the carrier plus exactly this 1x6 UART debug
header at J26. The carrier provides both, so **there is no E-28 deviation**; the 2x5
1.27 mm JTAG/SWD header described in earlier drafts is withdrawn and no JTAG connector is
fitted.

The DevKitC's two USB-C connectors are on the **non-isolated** side of the ADuM4160
barrier. They are used at the factory and on the bench only; the finished kit exposes only
the isolator module's host USB-C (E-24, S-03), and T18 checks that the enclosure does not
give a participant access to them.

### 2.4 `sdkconfig.defaults`, in full

This is the shipped file, verbatim. Every line is a requirement, not a preference.

*Corrected 2026-09-02.* The block below had stopped being verbatim. The five lines this
section used to list under "not yet in the file and must be added before the first build"
**are in the file now** -- they were added on 2 September when the first real build refused
to proceed without them -- and one of the five was named wrongly: there is no
`CONFIG_TINYUSB_VENDOR_ENABLED` in `esp_tinyusb` 1.4.x, and ESP-IDF warns rather than fails
on a key it does not recognise, so the setting looked present while `CFG_TUD_VENDOR` stayed
0 and the WebUSB interface did not exist. The key is `CONFIG_TINYUSB_VENDOR_COUNT`. The file
is re-quoted here as it stands, with its own commentary, because a section headed "in full"
that is not in full is worse than no quotation at all.

```
# FW-EEG-001 -- build configuration for EEG-CAR-01 Rev B.
# Every line here is a requirement, not a preference.  Changing one changes the instrument.

CONFIG_IDF_TARGET="esp32s3"

# ---- flash and PSRAM ------------------------------------------------------------
# The -N16R8 module has 16 MB quad flash and 8 MB OCTAL PSRAM.  The octal PSRAM uses
# GPIO35, 36 and 37, which is why those three pins are not connected on the carrier
# (ECO-EEG-009).
CONFIG_ESPTOOLPY_FLASHSIZE_16MB=y
CONFIG_ESPTOOLPY_FLASHMODE_QIO=y
CONFIG_ESPTOOLPY_FLASHFREQ_80M=y
CONFIG_SPIRAM=y
CONFIG_SPIRAM_MODE_OCT=y
CONFIG_SPIRAM_TYPE_AUTO=y
CONFIG_SPIRAM_SPEED_80M=y
CONFIG_SPIRAM_USE_MALLOC=y
CONFIG_SPIRAM_MALLOC_ALWAYSINTERNAL=4096

# ---- partitions ------------------------------------------------------------------
CONFIG_PARTITION_TABLE_CUSTOM=y
CONFIG_PARTITION_TABLE_CUSTOM_FILENAME="partitions.csv"
CONFIG_BOOTLOADER_APP_ROLLBACK_ENABLE=y
CONFIG_BOOTLOADER_APP_ANTI_ROLLBACK=y

# ---- USB ---------------------------------------------------------------------------
# GPIO19 and GPIO20 are the USB PHY.  Using TinyUSB in device mode takes the PHY away
# from the USB-Serial-JTAG console, so UART0 on GPIO43/44 is the only console -- which
# is why J26 exists.
CONFIG_TINYUSB_CDC_ENABLED=y
CONFIG_TINYUSB_CDC_COUNT=1
CONFIG_TINYUSB_DESC_USE_ESPRESSIF_VID=n
CONFIG_ESP_CONSOLE_UART_DEFAULT=y
CONFIG_ESP_CONSOLE_UART_NUM=0

# ---- radio: never initialised (RFQ E-18) --------------------------------------------
CONFIG_ESP_WIFI_ENABLED=n
CONFIG_BT_ENABLED=n

# ---- security (RFQ F-19) -------------------------------------------------------------
# Enabled for PHASE 2 ONWARD production builds only.  The Phase 1 prototypes are built
# with the sdkconfig.phase1 overlay and burn no eFuses.  The signing key never leaves the
# programme; the manufacturer flashes a pre-signed image.  See FW-EEG-001 section 7.5.
CONFIG_SECURE_BOOT=y
CONFIG_SECURE_BOOT_V2_ENABLED=y
CONFIG_SECURE_SIGNED_APPS_RSA_SCHEME=y
CONFIG_SECURE_BOOT_BUILD_SIGNED_BINARIES=n
CONFIG_SECURE_FLASH_ENC_ENABLED=y
CONFIG_SECURE_FLASH_ENCRYPTION_MODE_RELEASE=y

# ---- timing -----------------------------------------------------------------------
# The DRDY interrupt is the only place the sample counter moves (RFQ E-19), so it must
# be in IRAM and must not be delayed by a flash cache miss.
CONFIG_FREERTOS_HZ=1000
CONFIG_ESP_INT_WDT_TIMEOUT_MS=300
CONFIG_ESP_TASK_WDT_TIMEOUT_S=10
CONFIG_SPI_MASTER_ISR_IN_IRAM=y
CONFIG_GPIO_CTRL_FUNC_IN_IRAM=y

# ---- storage ------------------------------------------------------------------------
CONFIG_FATFS_LFN_HEAP=y
CONFIG_FATFS_MAX_LFN=255

# ---------------------------------------------------------------- added to close FW-D11
# FW-EEG-001 section 2.4 headed these "not yet in the file and must be added before the
# first build", and they were still absent.  Without the first three the vendor interface
# and the custom descriptor set do not exist, so WebUSB does not enumerate and the
# _Static_assert on the MS OS 2.0 descriptor length never gets a chance to fire.
# CONFIG_TINYUSB_VENDOR_COUNT, not CONFIG_TINYUSB_VENDOR_ENABLED.
#
# esp_tinyusb 1.4.x has no option called TINYUSB_VENDOR_ENABLED, and ESP-IDF does not fail
# on a key it does not recognise -- it warns and carries on.  So the setting looked present,
# CFG_TUD_VENDOR stayed 0, tusb.h declared none of the tud_vendor_* functions, and the
# WebUSB interface this device is built around would simply not have existed.  It surfaced
# as "implicit declaration of function 'tud_vendor_mounted'" the first time the firmware was
# put in front of a real compiler.
CONFIG_TINYUSB_VENDOR_COUNT=1
CONFIG_TINYUSB_DESC_CUSTOM=y
CONFIG_TINYUSB_TASK_PRIORITY=18
CONFIG_BOOTLOADER_APP_SECURE_VERSION=1
CONFIG_BOOTLOADER_APP_ANTI_ROLLBACK=y
CONFIG_ESP_TASK_WDT_EN=y
```

`CONFIG_SECURE_BOOT_BUILD_SIGNED_BINARIES=n` is deliberate. The build container never
holds the signing key; signing is a separate `espsecure.py sign_data` step performed on the
custodian's offline machine (section 7.5). `CONFIG_SECURE_SIGNED_APPS_RSA_SCHEME` selects
RSA-3072 for secure boot v2. That is independent of the ATECC608B's P-256 device key: one
authenticates firmware to the chip, the other authenticates recordings to the programme.

**The five lines this section used to call missing are now present**, and this is what
became of each. *Corrected 2026-09-02: the table below used to be headed "lines that are not
yet in the file and must be added before the first build".*

| Line | Status | Note |
|---|---|---|
| `CONFIG_TINYUSB_VENDOR_COUNT=1` | **added** | FW-D03. This row used to name `CONFIG_TINYUSB_VENDOR_ENABLED`, which is not an option that exists; see above |
| `CONFIG_TINYUSB_DESC_CUSTOM=y` | **added** | FW-D02. It supplies the descriptors as data; the three callbacks `main.c` also defined had to be **deleted**, not kept |
| `CONFIG_TINYUSB_TASK_PRIORITY=18` | **added** | sits below `sample_task` at 23, as required |
| `CONFIG_BOOTLOADER_APP_SECURE_VERSION=1` | **added** | `CONFIG_BOOTLOADER_APP_ANTI_ROLLBACK=y` is meaningless without it |
| `CONFIG_ESP_TASK_WDT_EN=y` | **added, and the subscription is not written** | The option is on. Nothing subscribes `sample_task` or the SD path to the watchdog, so a stalled SD write still does not reset the unit. That half is open and is carried in section 10 |

**Phase 1 overlay.** The five security lines above are off for the two Phase 1 prototypes,
which run **unsigned images and burn no eFuses at all**, so the firmware volunteer can
re-flash them at the bench. Build Phase 1 images with
`idf.py -DSDKCONFIG_DEFAULTS="sdkconfig.defaults;sdkconfig.phase1" build`, where
`sdkconfig.phase1` sets `CONFIG_SECURE_BOOT=n`, `CONFIG_SECURE_FLASH_ENC_ENABLED=n` and
`CONFIG_BOOTLOADER_APP_ANTI_ROLLBACK=n`. **That file is now in the package**, as
`firmware/sdkconfig.phase1`, and is listed in full below. Secure boot and flash encryption
are enabled from Phase 2 onward; see section 7.5.

The overlay is the whole of the phase switch. It turns security options off and adds none,
so a Phase 1 image and a Phase 2 image are the same firmware built two ways, and a Phase 1
prototype can be re-flashed at the bench for ever. `sdkconfig.defaults` is never edited to
move between phases -- editing it is how a prototype gets its eFuses burnt by accident.

**`sdkconfig.phase1`, in full:**

*Corrected 2026-09-02.* The quotation below had also stopped being verbatim, and the
divergence was load-bearing rather than cosmetic. The file had acquired a second block of
options appended after the ones quoted here, and one of them was
`CONFIG_BOOTLOADER_APP_ANTI_ROLLBACK=y` -- twenty lines below the deliberate `=n`. A later
duplicate of the same key silently wins, so the Phase 1 intent was being undone by a line
that read as an addition. It also made the build fail outright: ESP-IDF refuses
anti-rollback on a partition table carrying a `factory` partition, and `partitions.csv` has
one. That is how it was found -- the first real ESP-IDF build stopped there. The file is
re-quoted as it stands.

```
# FW-EEG-001 section 2.4 -- Phase 1 overlay for the two prototypes.
#
# Use:  idf.py -DSDKCONFIG_DEFAULTS="sdkconfig.defaults;sdkconfig.phase1" build
#
# Phase 1 prototypes run UNSIGNED images and BURN NO eFUSES (RUL-EEG-021 section B), so the
# firmware volunteer can re-flash them over UART indefinitely.  Do not put these lines in
# sdkconfig.defaults and do not build a Phase 2 unit with this overlay: a secure-boot-v2
# bootloader burns its eFuses on first boot, and with
# CONFIG_SECURE_FLASH_ENCRYPTION_MODE_RELEASE=y that unit can never be re-flashed over UART
# again.  Phase 2 onward builds from sdkconfig.defaults alone; see section 7.5.

CONFIG_SECURE_BOOT=n
CONFIG_SECURE_BOOT_V2_ENABLED=n
CONFIG_SECURE_SIGNED_APPS_RSA_SCHEME=n
CONFIG_SECURE_BOOT_BUILD_SIGNED_BINARIES=n
CONFIG_SECURE_FLASH_ENC_ENABLED=n
CONFIG_SECURE_FLASH_ENCRYPTION_MODE_RELEASE=n

# Anti-rollback is an eFuse mechanism.  With no eFuses burnt there is no anti-rollback and
# a downgrade is possible on a Phase 1 prototype; that is accepted and stated in section 7.5.
CONFIG_BOOTLOADER_APP_ANTI_ROLLBACK=n

# ---------------------------------------------------------------- added to close FW-D11
# FW-EEG-001 section 2.4 headed these "not yet in the file and must be added before the
# first build", and they were still absent.  Without the first three the vendor interface
# and the custom descriptor set do not exist, so WebUSB does not enumerate and the
# _Static_assert on the MS OS 2.0 descriptor length never gets a chance to fire.
# CONFIG_TINYUSB_VENDOR_COUNT, not CONFIG_TINYUSB_VENDOR_ENABLED.
#
# esp_tinyusb 1.4.x has no option called TINYUSB_VENDOR_ENABLED, and ESP-IDF does not fail
# on a key it does not recognise -- it warns and carries on.  So the setting looked present,
# CFG_TUD_VENDOR stayed 0, tusb.h declared none of the tud_vendor_* functions, and the
# WebUSB interface this device is built around would simply not have existed.  It surfaced
# as "implicit declaration of function 'tud_vendor_mounted'" the first time the firmware was
# put in front of a real compiler.
CONFIG_TINYUSB_VENDOR_COUNT=1
CONFIG_TINYUSB_DESC_CUSTOM=y
CONFIG_TINYUSB_TASK_PRIORITY=18
CONFIG_BOOTLOADER_APP_SECURE_VERSION=1
# NOT CONFIG_BOOTLOADER_APP_ANTI_ROLLBACK=y here.  It was appended in this block and it
# contradicted the deliberate `=n` twenty lines above, which explains why a Phase 1
# prototype has no anti-rollback: it is an eFuse mechanism and no eFuses are burnt.  A
# later duplicate of the same key silently wins, so the Phase 1 intent was being undone by
# a line that looked like an addition.  It also makes the build fail outright -- ESP-IDF
# refuses anti-rollback on a table that has a `factory` partition, and partitions.csv has
# one -- which is how it was found: the first real ESP-IDF build stopped here.
CONFIG_ESP_TASK_WDT_EN=y

# ---------------------------------------------------------------- IRAM headroom
# The first real build came back with static IRAM at 100.0 % -- 16,383 of 16,384 bytes,
# ONE byte free.  That is a cliff, not a pass: the next function anyone marks IRAM_ATTR
# fails the link with an error naming a section rather than a cause, and this design has
# more interrupt work coming (the E-13 tone scheduler, the E-12 onset detector).
#
# Two ISRs are kept in IRAM by default and neither is used by this firmware.  There is no
# SPI slave anywhere in the design -- the ESP32-S3 is the master and both ADS1299 modules
# are slaves -- and nothing uses gptimer; `grep spi_slave` and `grep gptimer` over main/
# return nothing.  Reclaiming them costs this design nothing.
#
# SPI MASTER stays in IRAM deliberately: sample_task() reads the converters on every DRDY
# and that path must survive a flash-cache stall.
CONFIG_SPI_SLAVE_ISR_IN_IRAM=n
CONFIG_GPTIMER_ISR_HANDLER_IN_IRAM=n
#
# MEASURED AFTERWARDS, AND IT DID NOT HELP.  The figure is still 16,383 of 16,384 with one
# byte free, byte for byte, so whatever fills that pool it is not these two ISRs.  The
# change is kept because carrying interrupt handlers for a bus and a timer this firmware
# does not use is wrong either way, but it is NOT the fix and must not be mistaken for one.
# Either the pool is genuinely full and a bring-up engineer has to choose what leaves IRAM,
# or esp_idf_size is reporting against a fixed 16 KB window that is not the real limit on
# an ESP32-S3 with octal SPIRAM and XIP.  Deciding which needs the linker map read against
# hardware, so it is carried as an open item rather than guessed at from here.
```

The three security lines named in the paragraph above are the ones that matter; the other
four are their dependants, set explicitly so that `idf.py` reports the same configuration on
every bench rather than resolving them silently.

Two blocks follow them and neither is a security line. The first repeats the FW-D02 /
FW-D03 / FW-D11 options of the previous subsection; an overlay build reads
`sdkconfig.defaults` first and then this file, so those four lines are **redundant rather
than load-bearing** -- they are kept because a reader of this overlay alone should be able
to see the whole of what a Phase 1 image is built with. The second is the pair of IRAM
lines, `CONFIG_SPI_SLAVE_ISR_IN_IRAM=n` and `CONFIG_GPTIMER_ISR_HANDLER_IN_IRAM=n`: an
attempt at the open item of section 9 that **did not work**, is kept for a different reason
than the one it was made for, and says so in the file.

**`sdkconfig.qemu` -- an emulator overlay, and not a configuration for any unit.** Added
2 September 2026 so the firmware could be run without hardware (section 8.2). It differs
from the shipped build in exactly one option, and that option is why the QEMU boot gets as
far as it does:

```
# FW-EEG-001 -- overlay for running the firmware under QEMU.
#
# NOT a build configuration for any real unit.  It exists so the firmware can be exercised
# without hardware, and it differs from the shipped build in exactly one way that matters.
#
# QEMU's esp32s3 machine does not emulate octal PSRAM.  The shipped configuration aborts
# when PSRAM is absent -- "Failed to init external RAM!" -- and the unit then reboots in a
# loop.  That is defensible on real hardware, because the 6 MiB ring buffer of F-06 lives
# in PSRAM and a unit without it cannot do its job; it is also, on a field device, a
# failure mode that says nothing to anyone. A unit that boot-loops in a participant's home
# cannot be told apart from a dead battery or a bad cable, and the browser tool cannot ask
# it what is wrong because it never gets far enough to enumerate. See KNOWN_ISSUES.
CONFIG_SPIRAM_IGNORE_NOTFOUND=y
```

Never build a unit with this overlay. `CONFIG_SPIRAM_IGNORE_NOTFOUND=y` turns a missing
6 MiB ring buffer -- which is F-06, and the whole of the retransmit story -- from a refusal
to boot into a silent degradation, and a field unit that records without a ring is a unit
that loses data the host asked it to keep.

### 2.5 `partitions.csv`, in full

```
# FW-EEG-001 partition table -- A/B OTA with rollback (RFQ F-20), 16 MB flash.
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

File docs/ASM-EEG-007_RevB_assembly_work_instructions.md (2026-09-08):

# ASSEMBLY WORK INSTRUCTIONS -- EEG FIELD KIT

**Document:** ASM-EEG-007  **Revision:** B  **Date:** 2026-09-01
**Issued by:** TI One Voice research programme (one.witysk.org), Brussels, Belgium
**Licence:** CC BY-SA 4.0
**Governing documents:** DSN-EEG-003 Rev D, then RFQ-EEG-001 Rev E. Where this
document and design.py disagree, design.py governs.

**Revision note, Rev A to Rev B:** the carrier is now 150.0 x 130.0 mm and FOUR layers,
so the part and hole census, the IQC check, the reflow profiling and the stack-up note are
all recomputed from `tools/design.py`; the enclosure grew to match; end-of-line flashing
moves from J26 to the DevKitC-1's own UART USB-C port; the standoff, the module count, the
socket-family list, the serial-number format, the host USB connection and the ICD
cross-references are corrected; the fiducial and E-28 open items are closed and replaced by
the open items that the layout work actually produced.

**Corrections within Rev B, 2026-09-02: this document is brought into line with the released
POD-P1-01 and HM-01 geometry.** Section 3.3's standoff, section 5.1 item 1's boss fixings,
item 3's harness entry, item 4's stack fixing and the stage 4 torque table all described a pod
that `tools/mech_gen.py` does not generate: the released base has eight Ø4.00 mm brass-insert
bores where this document expected Ø2.5 mm thread-forming pilots, two Ø12.50 mm cable-gland
harness entries where this document said there were none, and a carrier fixing that needs a
male-female standoff where section 3.3 bought a female-female one. **Where this document and
the released geometry disagree, the geometry is the fact and this document was wrong.** The
sizes and lengths the geometry needs are in `mech/HARDWARE_SCHEDULE.md`, generated from the
model by `tools/mech_gen.py`; the parts themselves are still to be chosen and that file says
so line by line. Section 4 gains the helmet end of the two umbilicals, which had no entry
geometry and no strain relief at all.

**Corrections within Rev B, 2026-09-02, after the design and firmware changes of that day.**
Two part values on the incoming-goods list changed and one open item closed, and the operator
must build to the new values: **R1 to R16 are 68 kΩ**, not 47 kΩ (ECO-EEG-024 applied, so
RFQ S-02 is met at 36.8 µA), and **C21, C41 and C61 are 10 nF C0G** with **C22, C42, C62 at
22 nF C0G** and their Sallen-Key resistors at **215 kΩ**, in place of the 100 nF X7R
compromise, so RFQ E-11 is met with the approved parts. Section 1.3, section 2's diode note,
section 4.3 and section 11 items 4 and 6 are restated for it, and **section 4.3's contact-light
phase driver now exists**. Build to the BOM and to `tools/design.py`, which govern: a board
stuffed with 47 kΩ or with 100 nF X7R is a board built to the superseded values.
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

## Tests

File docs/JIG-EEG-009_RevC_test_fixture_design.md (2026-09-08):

# TEST FIXTURE DESIGN

**Document:** JIG-EEG-009  **Revision:** C  **Date:** 2026-09-01
**Issued by:** TI One Voice research programme (one.witysk.org), Brussels, Belgium
**Licence:** CC BY-SA 4.0
**Governing documents:** DSN-EEG-003 Rev D, then RFQ-EEG-001 Rev E. Where this
document and design.py disagree, design.py governs. Step numbers are owned by
TST-EEG-004 Rev C and are never invented here.

## Why this document exists

DSN-EEG-003 Rev A.2 described the whole production test fixture in one sentence: "a
16-channel resistor-divider and reference-resistor fixture on a 1x22 socket mating J14, a
3-way DIN plug set for EMG, and a host PC running the open test tool." Nine of the eighteen
steps of the package v1 test flow depended on that sentence, RFQ-EEG-001 section 10 asks bidders to
price "Stencil, fixtures, test jig (one-off)" against it, and the fourteen-agent audit of
package v1 recorded it as blocking three separate ways: the fixture had no design, the 1000:1
divider had no accuracy budget, and the analogue reference the noise test is measured against
was not on the connector the fixture mates with. TST-EEG-004 Rev C now has thirty-one steps,
T00, T0 and T1 to T29; fourteen of them name a lettered fixture sub-assembly and three more --
T19, T20 and T25 -- name fixture hardware that carries no letter. This document designs the
four fixtures that test flow needs, states the arithmetic behind the one limit that matters
most, and prices and schedules one set so a manufacturer can fill in that line.

**No hardware in this package has been built or measured, and no safety engineer has reviewed
this design** (DESIGN_FACTS section 8, item 1). Every figure marked *calculated* is
calculated. *Corrected 2026-09-02 from "Nothing in this package has been built or measured":
the ESP32-S3 firmware is now built -- ESP-IDF v5.2.5, images and SHA-256 manifest in
`firmware/release/` -- and has run only under QEMU emulation. **No fixture has been built**,
and no RP2040 image for M1 or M2 exists (section 7).*

---

## 0. Scope and fixture register

| Fixture | Name | TST-EEG-004 Rev C steps served | Mates with |
|---|---|---|---|
| FIX-01 | Front-end injection, lead-off and contact-light fixture | T7a/b/c, T8, T9a, T9b, T10, T11, T22, T23 | J14, J30, J15-J17, J22 |
| FIX-02 | Audio loopback and onset fixture | T12a, T12b, T12c, T12d, T13, T17, and T28 once per lot | 3.5 mm jack at J27, boom capsule, room port, J22 |
| FIX-03 | Flashing and provisioning fixture | the flashing and provisioning operation that precedes T5b, then T6, T16 and T25 | DevKitC-1 UART USB-C port, J26 |
| FIX-04 | Harness, current-shunt and isolation-barrier fixture | T00 (module bench currents), T3, T4, T20, T21, T23, and the WH-EEG-008 section 9 harness acceptance | 12-way and 10-way harness ends, J13 and J24, ADuM4160 host USB-C, the applied-part group |

Instruments are not fixtures and are not designed here. The set assumes a 6.5-digit DMM with
4-wire ohms, a function generator, a 100 MHz oscilloscope, a 500 V DC insulation tester, a
bench supply with 0.1 mA current resolution and a host PC. It also assumes three instruments
that TST-EEG-004 section 5 requires and that no fixture in this document replaces: an **audio
analyser or calibrated interface** (level +/- 0.1 dB, residual THD+N <= 0.01 %, used at T17
and T28), a **contact thermometer or thermal camera** (+/- 2 degC, used at T3) and a **2.4 GHz
receiver or SDR with a near-field probe** (noise floor <= -90 dBm, used at T24). Section 6 says
which instruments must be bought specifically. The v1 audit's FXT-EEG-005 and FIX-EEG-010 are
superseded by FIX-01 and FIX-03 and recorded in ECO-EEG-016.

### 0.1 Fixture naming, and the mapping onto TST-EEG-004's part letters

Package v1 left two naming systems running side by side: TST-EEG-004 Rev B lettered the
fixture parts A to G, and this document numbered whole fixtures FIX-01 to FIX-04 while using
the word "Part" for something else entirely. A contract manufacturer reading both would have
built the wrong hardware. The naming is now **FIX-01 to FIX-04 with lettered sub-assemblies**,
**the table in TST-EEG-004 Rev C section 6.1 owns the letters**, and this document uses those
letters and no others. Where a piece of fixture hardware carries no letter there, it carries
none here either, and it is named by what it mates instead of being given a letter this
document invented.

This is the sub-assembly register. It is a **transcription of all seventeen rows of
TST-EEG-004 Rev C section 6.1** for the reader who has only this document in front of them,
not a second definition; where the two differ, TST-EEG-004 section 6.1 governs. An earlier
draft of this revision carried only twelve of the seventeen and moved three of the letters
onto different hardware; that is corrected here. The last column says where each row is built
in this document, or says plainly that it is not built here.

| Sub-assembly | Mates | Contents | Built in this document at |
|---|---|---|---|
| **FIX-01/A** | J14, 1x12, keyed, pin 1 marked E_Fz | eleven channel networks: 1000:1 tap, selectable **4k99 / 10k0 / 49k9** 0.1 % thin-film reference, short-to-common, open. Relay-switched, state readable by the host tool | J103; sections 1.2, 1.5 and 1.8 |
| **FIX-01/B** | J15, J16, J17 DIN 42802 1.5 mm, 12 mm pitch | three identical channel networks for EMG1 cheek, EMG2 submental, EMG3 laryngeal | J105; sections 1.2 and 1.8 |
| **FIX-01/C** | J22.2 (AGND_REF), second position TP13 | analogue reference lead, marked "ANALOGUE REFERENCE -- NOT DGND" | J106 pin 2; sections 1.2 and 1.8 |
| **FIX-01/D** | all eleven J14 analogue pins and SRB1 | common-mode injection network, one source into all inputs through matched 100 Ohm | section 1.11: LK1 opened, the fixture common driven 1 V RMS at 50 Hz from an isolated source, reaching the inputs through the matched RS1-RS16 100 Ω series resistors of section 1.8. It is a state of FIX-01, not a separate head, and section 1.11 is where it is specified |
| **FIX-01/E** | J30, 1x10 | TCS34725-class colorimeter head over the eight contact-light positions, reading the R/G ratio at each site | J104; sections 1.7 and 1.8 |
| **FIX-01/F** | the FIX-01 injection input, with a DMM tap | the 1000:1 ratio divider, two cascaded stages, 100:1 then 10:1, feeding FIX-01/A, FIX-01/B and FIX-01/G | section 1.3 and its accuracy budget; R101-R104, U1, U2 and the J102 monitor in section 1.8 |
| **FIX-01/G** | J22, 1x3 | spare-channel injection for EOGIN1 (J22.1) and EOGIN2 (J22.3) | J106; sections 1.2 and 1.8. An earlier draft of this revision called this head FIX-01/D |
| **FIX-02/A** | the boom capsule, windscreen removed | voice coupler, 2.0 cm3, delivering 70.0 dB SPL at 1 kHz at the capsule | section 2.2; BOM at 2.4 |
| **FIX-02/B** | the room-microphone port and its mesh | room coupler, 3.5 cm3, sealed over the port | section 2.2; BOM at 2.4 |
| **FIX-02/C** | the shipped headphone model | IEC 60318-1 artificial ear and the class 1 sound level meter mount | **Not built here.** It is in neither the section 2.4 bill of materials nor the section 6 cost tables, so the one-off price in section 6 is short by that coupler and that meter. Stated as an open item in section 7 (section 2.1) |
| **FIX-02/D** | J27 headphone pigtail, and a scope tap | 47.0 Ohm load and the electrical-onset marker | sections 2.1 and 2.3; RL201, RL202, U201, R201, R202 and the TRS plug in the 2.4 BOM. An earlier draft of this revision lettered it "FIX-02" |
| **FIX-03/A** | DevKitC-1 UART USB-C port, card reader, host PC | flashing and provisioning nest | section 3.3: the PA12 nest, the sprung right-angle USB-C pigtail, the barcode scanner and the powered hub |
| **FIX-03/B** | J26, 1x6 | console and recovery lead. **It cannot enter download mode**, because GPIO0 is LED_SR_LATCH | section 3.3: the six-pin P75-B1 pogo block on J26, used for console capture with the UART pigtail unplugged. Section 3.2 rule 1 governs -- the pigtail and the pogo block are never connected at the same time |
| **FIX-04/A** | J13 and J24 JST PH pigtails | two 1.000 Ohm 0.1 % shunts, one in the battery line and one in the charge line | section 4.1, and read at the FIX-01 shift start (section 1.12) |
| **FIX-04/B** | host-side USB shell, VBUS, D+ and D- on the ADuM4160 | insulation head that reaches the module without touching the carrier | sections 4.1 and 4.2 |
| **FIX-04/C** | applied-part group and protective earth | 100 kOhm 0.1 % measuring resistor, screened, and the earth lead | sections 4.1 and 4.3 |
| **FIX-04/D** | 12-way electrode end, 10-way light end, three EMG snap leads | harness continuity and pull heads | section 4.1: the 12-way electrode head, the 10-way light head and the EMG head, with the 24-channel scanner card that switches them. The limits are WH-EEG-008 section 9, steps H1 to H10 |

TST-EEG-004 Rev B's "Part A" to "Part G" map onto that register as follows, so that every
older step reference still resolves. This is TST-EEG-004 section 6.1's own mapping and is
copied, not derived.

| TST-EEG-004 Rev B part | Now |
|---|---|
| A | FIX-01/A |
| B | FIX-01/B |
| C | FIX-01/C |
| D | FIX-02/D |
| E | FIX-01/E |
| F | FIX-04/A |
| G | FIX-01/G |

Identifiers this document has used and now **withdraws**, listed so that a reader holding an
earlier draft can find where each thing went:

| Withdrawn | Replaced by |
|---|---|
| FIX-04/H-D, the barrier insulation head | **FIX-04/B** |
| H-A, H-B and H-C, the harness heads of section 4.1 | **FIX-04/D**, which TST-EEG-004 section 6.1 calls the harness continuity and pull heads. An earlier draft of this revision said that table gave the heads no letter; it gives them FIX-04/D, and the three heads keep their descriptive names inside it |
| CPL-V and CPL-R, the acoustic couplers | **FIX-02/A** and **FIX-02/B** |

Three designators an earlier draft of this revision moved are **reassigned, not withdrawn**,
because TST-EEG-004 section 6.1 carries all three: **FIX-01/F** is the 1000:1 divider of
section 1.3, and the 1.000 Ω shunt pigtails that draft lettered FIX-01/F are **FIX-04/A**
(section 4.1); **FIX-01/G** is the spare-channel head into J22, which that draft renamed
FIX-01/D; and **FIX-02/D** is the 47.0 Ω load and electrical-onset marker of section 2.1,
which that draft lettered plain "FIX-02". A reader holding the intermediate draft should read
its FIX-01/D as FIX-01/G throughout: in TST-EEG-004 section 6.1, FIX-01/D is the common-mode
injection network for T9b.

The SHR-14-A, SHR-30-A and SHR-22-A shroud identifiers used in Rev A of this document are
**withdrawn**; PARTS-EEG-019 records them as legacy. The keying part is now WH-KEY-01, and
section 1.10 says how the fixture uses it. The 100 kΩ measuring resistor of T23 was called an
instrument rather than a fixture in an earlier draft of this revision; TST-EEG-004
section 6.1 makes it
FIX-04/C, and section 4.3 now builds it as one.

### 0.2 What changed in the carrier, and what it means for the fixtures

Two carrier changes happened during layout, after package v1 was written, and both are
engineering findings rather than preferences. They reach this document through the FIX-03
nest, the FIX-01 head coordinates and the checks that depend on the reference planes.

**The carrier is 150.0 x 130.0 mm**, not the 130 x 124 mm of package v1. Thirty connectors,
211 parts and 156 nets would not close at the smaller size, and the extra 33.8 cm² of bare board
costs a few euro per unit against a real risk of an unroutable design.

**The carrier is a four-layer board:** L1 signal, L2 reference plane, L3 reference plane, L4
signal. Package v1 asserted that two layers would be enough and would be cheap and easy to
route. Actually doing the layout showed it is not: on two layers the bottom side has to be
both the reference plane and the second routing surface, and it cannot be both. Four layers
give two full routing surfaces and a continuous reference under every analogue trace, which is
what DSN-EEG-003's layout rules require and which a swiss-cheesed two-layer pour cannot
deliver. At two units the four-layer board costs about €35 more in total; at fifty units it is
about €3 per board.

| Property | Value |
|---|---|
| Outline | 150.0 x 130.0 mm, rectangular, no cut-outs |
| Layers | four: L1 signal, L2 reference plane, L3 reference plane, L4 signal |
| Stack-up | mask / 35 µm L1 / prepreg 0.200 / 17 µm L2 / core 1.065 / 17 µm L3 / prepreg 0.200 / 35 µm L4 / mask = 1.60 mm ± 10 % |
| Reference planes | AGND_REF left of x = 62 mm, DGND right of it, on **both** L2 and L3, tied together by stitching vias |
| Vias | through vias only -- no blind, buried, back-drilled, filled or plugged -- 0.60 mm pad on a 0.30 mm finished hole |
| Mounting holes | M3, 3.2 mm NPTH at (5,5), (145,5), (5,125), (145,125), 6 mm copper keep-out |

The routing statistics for the four-layer board come from the DRC report at
`kicad/EEG-CAR-01_RevB_DRC_report.txt` and not from this document. EEG-CAR-01 Rev B is routed
on four layers with **3 745 track segments and 552 through vias**, and each reference plane is
one continuous island per net. **All 145 nets are fully connected**, none unclosed and none
without copper. Every rule passes: the smallest measured clearance is 0.260 mm on L1, 0.285 mm
on the planes and 0.275 mm on L4 against a 0.20 mm rule; the narrowest conductor is 0.20 mm and
the smallest plated hole is 0.30 mm; no copper comes within 2.00 mm of a non-plated hole; there
are no zone crossings; no digital net enters the analogue zone; and there is exactly one
AGND_REF-to-DGND bridge and one HARN_SHIELD-to-DGND bridge. The report lists no isolation
keep-out violation and no via keep-out violation, so the isolation strip is copper-free on all
four layers, which is what item 4 below relies on and the reason it is stated as a checked
result rather than an assumption.

**The board closes: zero DRC violations.** The report's own line is "VIOLATIONS: 0 -- none.
The board passes every rule listed above." Zero violations, every net one connected copper
island and both inner planes continuous under the analogue zone are the three conditions
ECO-EEG-016 section 3 sets for releasing fabrication data, and all three are met. **That was
not enough, and Rev B is withdrawn from fabrication.** An external layout engineer read the
board between 3 and 5 September 2026, declined the review and advised a redesign; his seven
findings are ECO-EEG-016 section 2, ECO-EEG-030, and six of them are rules the programme's DRC
was never given. **Nothing is released for fabrication or for review**: Rev C is unrouted and
its layout is bought. Nor did Rev B close comfortably. **169 connections are relaxed** -- 36 take a conductor narrower than the 0.25 mm
preferred width, and 133 keep full width and take a reduced gap -- all at or above the 0.20 mm
minimum conductor and the 0.20 mm minimum gap. A board that closes at minimum geometry is not
the same board as one that closes at preferred geometry, even when every rule passes, and the
fixtures are designed against a board nobody has yet fabricated or measured.

Consequences for the fixtures, and they are the reason this section is here rather than in an
annex:

1. The FIX-03 nest is dimensioned to 150.0 x 130.0 mm on the four M3 holes above. A nest cut
   for the v1 outline will not accept a Rev B carrier.
2. Every head coordinate in section 1.10 is taken from `tools/design.py` at the new outline.
3. The T19 star-point check and the T0 bare-board isolation now have to hold across **four**
   copper layers, not two. The star-point rule itself -- AGND_REF to DGND at R90 only,
   HARN_SHIELD to DGND at R91 only -- lives in DSN-EEG-003 section 3.3 and is not restated
   here.
4. The isolation keep-out is copper-free on **all four layers**, and that is a result read
   from the DRC report rather than an assumption: the report lists no isolation keep-out
   violation. Its coordinates and the star-point rule live in DSN-EEG-003 section 3.3;
   FIX-04 works to that section.

The fixtures' own printed circuit boards are unaffected: they stay two-layer, and section 1.9
says so explicitly so that nobody reads the carrier's stack-up onto them.

### 0.3 Programming and debug access -- no deviation remains

RFQ-EEG-001 Rev E E-28 asks for TP1 to TP18 on the carrier plus a 1x6 UART debug header at
J26 carrying DVDD3V3, DGND, UART_TX, UART_RX, RESET_EN and NC_GPIO0. EEG-CAR-01 Rev B carries
exactly that. The 2x5 1.27 mm JTAG/SWD header of RFQ Rev C is **withdrawn**: the ESP32-S3 is
programmed over UART0 and its native USB, and no JTAG connector is fitted. J26 way 6 is a
spare way named `NC_GPIO0` because GPIO0 is committed to LED_SR_LATCH (ECO-EEG-009) and does
not reach J26. FIX-03 is designed to that board, and the "E-28 deviation" open item carried in
Rev A of this document is deleted rather than answered.

---

## 1. FIX-01 -- front-end injection, lead-off and contact-light fixture

### 1.1 What it has to do

One function generator drives all sixteen protected inputs at once. That is not a convenience:
E-04's gain limit is *channel-to-channel matching within 0.5 %*, which is a ratio, and a ratio
measured against a source common to every channel at the same instant is free of the
generator's amplitude error entirely. Driving channels one at a time would put the generator's
+/-1 to 2 % amplitude accuracy straight into a 0.5 % limit, and would turn T7 into a 48-minute
sequential test instead of a 6-minute parallel one.

Absolute gain is a different quantity: the per-channel constant F-18 writes into NVS, recorded
rather than judged. FIX-01 produces it from an internal DC substitution source traceable to the
volt, not from the generator.

### 1.2 Architecture, in text-schematic form

```
J101 BNC  ---LK1--- [generator screen to FIX_COM; OPEN for T9b]
   centre --o K103.A (SIN)
                          +-------------------- J102 BNC monitor (DMM at the
                          |                     divider INPUT -- this node is
                          |                     measured, never commanded)
U3 ADR4550 5.0000 V --o K103.B (CAL)
   via K101/K102 DPDT polarity reversal, 5 s dwell each polarity
                          |
                     SRC_HI node
                          |
                    R101 9k90  (A1, ratio network, 99:1)
                          |
                    +-----+----- SRC_MID  (10 mV from 1 V; 5.0000 mV from 5.0000 V)
                    |     |
                  R102 100R    U1 OPA189 unity buffer, out = GRD_DRV
                    |            |
                 FIX_COM         +--> U2 OPA189 unity buffer --> GUARD pour
                                 |
                            R103 180R  (A2, ratio network, 9:1)
                                 |
                          +------+----- SRC_LO  (1/1000 of SRC_HI, Zo = 18 R)
                          |      |
                       R104 20R0 |
                          |      |
                       FIX_COM   +---- SRC bus, guarded, to 16 channel networks

per channel n (n = 1..16), all five relays open = OPEN:
   SRC bus --K(5n-4)--+
   RA(n) 4k99 --K(5n-3)--+
   RB(n) 10k0 --K(5n-2)--+---- RS(n) 100R 0.1% ---- channel pin n
   RC(n) 49k9 --K(5n-1)--+
   FIX_COM --K(5n)-------+      [SHORT position]
   (RA/RB/RC return to FIX_COM)

channel pins 1..11  -> J103, 12-way plug, into J14        [FIX-01/A]
channel pins 12..14 -> J105, 3-way DIN plug bar, J15/J16/J17  [FIX-01/B]
channel pins 15,16  -> J106, 3-way plug, into J22 pins 1 and 3 [FIX-01/G]
FIX_COM             -> J106 pin 2 = J22.2 = AGND_REF      [FIX-01/C]
lights              -> J104, 10-way plug, into J30        [FIX-01/E]
1.000 R shunts      -> J108/J109, JST PH pigtails, J13 and J24  [FIX-04/A]
```

FIX_COM is the fixture common. It reaches the DUT at exactly one point, J22 pin 2, which is
AGND_REF in the Rev B netlist. This closes the v1 audit finding that T8's "inputs shorted to
AGND_REF" had no defined return: on Rev A the reference was not on the harness connector at
all. On Rev B it is on J22, and the FIX-01/C lead is marked **ANALOGUE REFERENCE -- NOT
DGND**. TST-EEG-004 section 6.1 gives FIX-01/C two positions, TP13 and J22 pin 2; both are
built, and the J22 position is the one used for T8 because it is inside the protection
network rather than behind it.

The short for T8 is taken **at the connector pins**, so R1-R16 and C1-C16 stay in circuit.
That is the chain a participant is connected to, and its Johnson noise is part of the 1.0 µV
budget of E-03, not something to be engineered out of the measurement. The 68 kΩ noise and
flatness arithmetic lives in RISK-EEG-011 section 4 and is not repeated here; **RISK-EEG-011
still runs it at 47 kΩ and is owed the same correction**.

**R1-R16 are 68 kΩ.** *Corrected 2026-09-02: this paragraph read "R1-R16 are 47 kΩ on the
Phase 1 prototypes and do not stay that way. ECO-EEG-024 raises them to 68 kΩ before Phase 2
... when that ECO is cut, every lead-off expectation in section 1.6 and every calculated value
in TST-EEG-004 T10 must be recomputed at 68 kΩ."* The ECO is cut: `tools/design.py` fits
68 kΩ, and the recomputation it called for is done -- section 1.6's expectations and
TST-EEG-004 T10's calculated values are now the 68 kΩ set, and the T8 noise expectation is
0.31 µV RMS. E-10 sits at its +/-1.0 dB branch at the fitted 68 kΩ and was +/-0.5 dB at
47 kΩ; both states are stated together everywhere they appear. **The fixture hardware does not
change**, which is why this is a correction to wording and arithmetic and not to a design.
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

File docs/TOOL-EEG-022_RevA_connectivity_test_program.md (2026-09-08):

---
title: "EEG FIELD KIT — CONNECTIVITY TEST PROGRAM"
subtitle: "TOOL-EEG-022 Rev A · functional specification, technical description and user manual"
---

**Document:** TOOL-EEG-022 **Revision:** A **Date:** 1 September 2026
**Governing documents:** DSN-EEG-003 Rev D, then RFQ-EEG-001 Rev E, then FW-EEG-001 Rev D
section 5, which is normative for the wire format.
**Licence:** source MIT, this document CC BY-SA 4.0.
**Status:** the tool is written and its logic is tested against a simulated device. **It has
never been run against real hardware, because no unit has been built.**

---

## Part 0 — What this is, in one paragraph

A single HTML file. You double-click it, it opens in Chrome or Edge, you plug the EEG
instrument into a USB port, press one button, and it tells you whether the computer and the
instrument can talk to each other. It takes no measurement, touches no electrode, starts no
recording and contacts no server. It exists so that when something does not work, you can
find out in thirty seconds whether the problem is the cable, the computer, the browser or
the firmware — before anyone starts blaming the electronics or the study protocol.

---

# Part 1 — Functional specification

## 1.1 Why it exists

The end architecture of the study is:

```
   EEG instrument  ──USB──▶  participant's computer  ──WebSocket──▶  TI One Voice server
                             (Chromium browser)
```

Three links, three ways to fail, and only one of them is the instrument. When a participant
says "it does not work", the programme needs to know which link broke without shipping the
kit back. This tool tests the first link on its own, in isolation, on the participant's own
computer.

It is also the first thing a manufacturer runs after assembling a unit, before the full
production test of TST-EEG-004: if TOOL-EEG-022 fails, nothing in TST-EEG-004 will pass and
there is no point starting it.

## 1.2 What it must do (requirements)

| # | Requirement | Level | Verified by |
|---|---|---|---|
| T-01 | Run in a Chromium browser on Windows and macOS with no installation, no server, no compiler and no administrator rights | M | Part 3, step 1 |
| T-02 | Open the instrument over Web Serial using the same code path the study runner will use | M | shared `transport.js`, step D1 |
| T-03 | Confirm the tool's own protocol implementation before testing anything else | M | steps S1–S3 |
| T-04 | Read the device's identity — serial, firmware, board revision, capabilities — without starting a session | M | step D1, `CMD_IDENTIFY` |
| T-05 | Prove the full frame path in both directions: COBS, CRC-32, both USB endpoints, the ack path | M | steps D4–D6, `CMD_LOOPBACK` |
| T-06 | Detect a transport that corrupts particular byte values | M | step D6, 256-value sweep |
| T-07 | Measure command round-trip latency | S | step D7 |
| T-08 | Confirm the device is silent when no session is running | M | step D8 |
| T-09 | Take no measurement, energise no electrode, write nothing to the microSD card | M | Part 2.6 |
| T-10 | Contact no network endpoint of any kind | M | `build.py` refuses to emit a file with an external reference |
| T-11 | Produce a saved report an operator can attach to an email or a device history record | S | Part 3, step 6 |
| T-12 | Share its protocol, transport and sink code with the production study runner, with no second implementation of the wire format | M | Part 2.2 |

## 1.3 What it deliberately does not do

- **It does not measure anything.** No channel is decoded, no impedance is checked, no
  electrode is read. A pass says the link works; it says nothing about signal quality,
  electrode contact, noise, or whether the instrument is safe to put on a person.
- **It does not connect to the server.** There is no network code in the delivered file, and
  the build refuses to produce one that has any.
- **It does not write to the device.** The two commands it sends are read-only by
  construction: one asks for an identity, one asks for an echo. Nothing is provisioned,
  configured or stored.
- **It is not a substitute for TST-EEG-004.** It is one page of the production test's first
  step, made runnable on its own.

---

# Part 2 — Technical description

## 2.1 Files

```
webtest/
  EEG-Connectivity-Test.html   THE DELIVERABLE. One self-contained file, ~48 kB.
  index.html                   the same page, loading the modules below (development)
  build.py                     inlines the modules into the deliverable
  js/
    protocol.js                COBS, CRC-32, the 10-byte header, framing, sequence tracking
    transport.js               Web Serial port, read loop, command/ack round trips
    sinks.js                   the FrameSink interface, and the production upload sink
    diagnostics.js             the test sequence S1-S5 and D1-D8
    ui.js                      the screen. Small on purpose
  tests/
    protocol.test.mjs          COBS, CRC, framing, sequence wrap  (node tests/…)
    roundtrip.test.mjs         the whole exchange against a simulated device, in JS
    interop/                   the same exchange against the REAL firmware
      run.sh                   sh webtest/tests/interop/run.sh
      harness.c                compiles firmware/main/main.c against ESP-IDF stubs
      drivers_sim.c            simulated peripherals implementing drivers.h
      host.mjs                 drives it with this tool's own protocol.js
      stubs/                   the minimum FreeRTOS/TinyUSB/driver headers to compile
```

**Why `interop/` exists, when `roundtrip.test.mjs` already tests the exchange.** That test
drives the real host code against a device simulated *in JavaScript*, written by hand from
the same specification as `main.c`. Both drifted from that specification, independently and
in different directions -- and every JS test passed throughout, because the JS host and the
JS device shared one misunderstanding. `interop/` removes the shared author: it compiles the
actual firmware translation unit, wires stdin and stdout to the simulated USB endpoints, and
drives it with the actual `protocol.js`. It needs a C compiler and Node, no ESP-IDF and no
hardware, and it runs 32 checks in a couple of seconds. It found the defect that made every
command from this tool start a recording session.

## 2.2 Architecture, and why the tester is production code

The tool is **not** a throwaway page. Everything except `ui.js` and `diagnostics.js` is the
browser client the study will use, written once:

```
        ┌────────────────────────────────────────────────┐
        │  protocol.js   COBS · CRC-32 · frames · seq    │  shared, normative
        ├────────────────────────────────────────────────┤
        │  transport.js  Web Serial · command/ack        │  shared
        ├────────────────────────────────────────────────┤
        │  sinks.js      FrameSink interface             │  shared
        │     ├── InspectorSink   ← this tool            │
        │     └── UploadSink      ← the study runner     │
        └────────────────────────────────────────────────┘
```

`FrameSink` is the seam. A sink obeys three rules, and each comes from a requirement rather
than from taste:

1. **`accept()` must not block the read loop.** At 1000 Hz a frame arrives every 20 ms and
   USB will not wait. A sink that needs time queues and returns.
2. **A sink must be able to report backpressure.** F-06's ring buffer and `CMD_RETRANSMIT`
   exist so that a host which falls behind can catch up rather than lose data. A sink that
   cannot say "I am behind" makes both useless.
3. **A sink must never silently drop.** F-07: silent loss is not permitted. If it discards,
   it counts, and the count is visible.

`UploadSink` — the server path — is written, commented and **shipped unused**. It is not
called by this tool and connects to nothing. It is included because writing it is what
proves the interface is the right shape, and because the four things it needs from the
server are the four things easiest to get wrong when the server is designed: an ordered
framed channel rather than a series of POSTs; backpressure the client can observe; an ack
carrying the highest contiguous sequence durably stored; and a resume handshake so a dropped
socket does not lose a block. **It has never been tested against a server, because no server
endpoint exists.**

## 2.3 The two firmware commands

Added to FW-EEG-001 for this tool. Neither touches the converters, the electrodes, the codec
or the card, so both are safe on a bare bench unit.

| Opcode | Name | Request | Reply |
|---|---|---|---|
| `0x0F` | `CMD_IDENTIFY` | none | 14 bytes + NUL-terminated serial: proto version, firmware major/minor, board revision letter, ring bytes (u32 LE), capability flags (u32 LE), current rate code, number of supported rates |
| `0x10` | `CMD_LOOPBACK` | up to 240 bytes | the same bytes, unchanged |

**Both results arrive in the acknowledgement envelope of FW-EEG-001 section 6.2, not bare.**
The CMD_ACK payload is `[0]` the opcode echoed, `[1]` reserved zero, `[2]` the status code,
`[3]` the result length, `[4..]` the result. `parseAck()` in `js/protocol.js` is the only
place that knows this; `identify()` and `loopback()` read `ack.result`.

*Corrected 2026-09-02.* The firmware, this tool and the specification had three different
answers to this question. FW-EEG-001 section 6.2 has always specified the envelope above.
`main.c` emitted `{ opcode, status }` with the status at offset 1 and no length, and
`CMD_IDENTIFY`, `CMD_LOOPBACK` and `CMD_CLOCK_XCHG` bypassed even that and returned their
result at offset 0. This tool read the identity struct from offset 0, so it agreed with the
firmware by accident on one command and with nothing on the others. All three now agree, and
`webtest/tests/interop/` exists to keep them that way -- it compiles the real `main.c` and
drives it with the real `protocol.js`, which is the only test here that can catch the two
sides drifting together.

The echo matters beyond tidiness. `transport.js` matches each reply to the command that
asked for it **by opcode**. Before the echo existed on every reply it matched by arrival
order, so one command timing out made every later reply answer the wrong promise.

Capability flags: bit 0 CDC, 1 WebUSB, 2 microSD mounted, 3 codec initialised, 4 ATECC
present, 5 provisioned (config zone locked).

*Corrected 2026-09-02.* Bit 3 was documented here and displayed by this tool, and `main.c`
never set it under any condition, so a working codec always read as absent. Bit 4 was set
only when the ATECC's configuration zone was **locked**, which conflates "the part is
fitted" with "the unit has been provisioned" -- so a good board coming off the line reported
no secure element at all, at exactly the moment a production tester is asking whether the
part is there. Bits 3 and 4 now mean what this table says they mean, and bit 5 alone carries
provisioning.

`CMD_LOOPBACK` is the more valuable of the two. `CMD_IDENTIFY` proves the device answers;
the loopback proves the **whole path** — COBS stuffing, the CRC, the sequence counter, both
USB endpoints and the ack dispatch — in one round trip, with a payload the host chose.

## 2.4 The test sequence

**Self-checks, no device required.** If any of these fails, the tool or the browser is at
fault and no conclusion may be drawn about a unit.

| # | Check | Fails when |
|---|---|---|
| S1 | CRC-32 against the standard check value `crc32("123456789") = 0xCBF43926` | the implementation is wrong |
| S2 | COBS round trip over four payloads, including all-zero and a run longer than 254 bytes | the stuffing is wrong |
| S3 | A frame this tool builds is one this tool can parse | the two halves disagree |
| S4 | `navigator.serial` exists | Safari, Firefox, or a mobile browser |
| S5 | The page is a secure context | served over plain `http://` from somewhere other than localhost |

**Device checks.**

| # | Check | What a failure means |
|---|---|---|
| D1 | The device answers `CMD_IDENTIFY` | no firmware, wrong firmware, or the cable is charge-only |
| D2 | Protocol versions match | one side is older; do not interpret the frames |
| D3 | The unit serial is provisioned | *warning only.* End-of-line provisioning has not run. The link is fine; the browser cannot bind a persistent authorisation to this unit (F-04) |
| D4 | Loopback, 5 bytes including `0x00` and `0xFF` | basic framing |
| D5 | Loopback, a full 240-byte payload | buffer sizing at both ends |
| D6 | Loopback sweep across all 256 byte values | a transport that mangles particular values — a COBS bug, or a driver doing newline translation |
| D7 | Round-trip latency, 20 commands, median and p95 | *warning above 50 ms.* Suspect a hub, a virtual COM driver, or a busy machine. Matters because the stimulus timing of E-13 depends on it |
| D8 | The link is quiet for one second | *warning if not.* A session is already running, or the firmware streams without being asked |

**Frame integrity**, counted over everything received since the port opened: bytes in,
frames decoded, CRC errors, version errors, short frames, resyncs, oversize discards,
sequence gaps, frames missing. On a healthy link every error row is zero.

## 2.5 Why one file, and why `file://` works

Web Serial requires a *secure context*. Chromium treats `file://` as
potentially trustworthy, so a double-clicked local file qualifies and no server is needed.

Module **files**, however, are blocked by CORS from a `file://` page — a page that does
`<script type="module" src="js/ui.js">` shows a blank screen. An **inline**
`<script type="module">` has nothing to fetch and runs normally. So the source stays as
modules, and `build.py` inlines them into `EEG-Connectivity-Test.html`.

That is also the honest answer to "a compiled runtime for Windows and macOS": there is
nothing to compile. One file, both operating systems, no installer, nothing to sign, nothing
to trust beyond a file you can read.

`build.py` will refuse to emit the deliverable if it still references any local file or any
network resource, so T-10 cannot be broken by accident.

## 2.6 Safety

The tool cannot energise anything. It sends two opcodes, neither of which reaches the
ADS1299 converters, the bias drive, the audio codec or the microSD card, and the device is
battery-powered and galvanically isolated from the computer by the ADuM4160 module (E-24)
whether this tool is running or not.

It is nevertheless **not** a substitute for the electrical safety review of RISK-EEG-011
section 7. A passing connectivity test says nothing about patient safety and must never be
quoted as if it did.

## 2.7 What was found while writing it

Writing a host that parses the wire format exposed a firmware defect that no document had
caught, now registered as **FW-D19**:

> The frame header was copied onto the wire with `memcpy(txbuf, &h, sizeof h)`, and
> `sizeof(frame_hdr_t)` is **12, not 10**. The struct is tail-padded to its four-byte
> alignment, so two padding bytes sat between the header and the payload. Every host parser
> written to FW-EEG-001 section 5.1 — including this package's own
> `firmware/tools/verify_stream.py`, which unpacks `"<BBHIBB"` — would have misparsed every
> frame by two bytes.

Fixed by serialising the header field by field, with a `_Static_assert` on the ten-byte
length. A wire format is a contract with other people's software and must never be a struct
copy.

---

# Part 3 — User manual

## What you need

- The EEG instrument and its USB cable.
- A computer running **Windows 10 or later** or **macOS 11 or later**.
- **Google Chrome** or **Microsoft Edge**. Safari and Firefox will not work — they do not
  implement the browser feature that talks to USB devices, and no setting changes that.
- The file `EEG-Connectivity-Test.html`.

You do not need to install anything, you do not need administrator rights, and you do not
need an internet connection.

## Step 1 — Open the tool

Double-click **`EEG-Connectivity-Test.html`**.

If it opens in the wrong browser, right-click it and choose *Open with* → *Google Chrome*
(or *Microsoft Edge*).

The page tells you, near the top, which browser it is running in. If it says Safari or
Firefox, close it and open it in Chrome or Edge.

## Step 2 — Check the tool checks itself

Section 2, *The tool checks itself*, fills in immediately. All five lines should show a green
tick. If any shows a red cross, stop: the problem is the browser or the file, not your
instrument, and the line tells you which.

## Step 3 — Plug in the instrument

Use the supplied USB cable. Connect it to the socket on the pod, and to a USB port **on the
computer itself** — not through a hub, a monitor or a docking station, if you can avoid it.

## Step 4 — Choose the device

Press **Choose the device**.

Your browser shows a small window listing the USB devices it can see. Choose the EEG
instrument and press *Connect*.

- **If the list is empty**, the computer cannot see the instrument. Try a different cable —
  many USB cables carry power only and no data — then a different port. If it is still
  empty, the instrument is not powered or its firmware is not running.
- **If you press Cancel**, nothing happens and you can press the button again.

## Step 5 — Run the test

Press **Run the connectivity test**. It takes a few seconds.

The bar under the buttons then reads one of:

| | What it means | What to do |
|---|---|---|
| **PASS** | The computer and the instrument talk to each other correctly. | Nothing. Carry on. |
| **PASS WITH WARNINGS** | The link works, but something is worth knowing. | Read the amber lines. The common one is *Unit serial is provisioned* — normal on a new unit that has not been through end-of-line provisioning. |
| **FAIL** | The link does not work. | Read the red lines; each says what failed. Try steps 3 and 4 again with a different cable and a different port before reporting a fault. |

## Step 6 — Save the report

Press **Save the report**. Your browser saves a small `.json` file to your Downloads folder,
named after the instrument's serial number and the time.

Attach that file to your email if you are reporting a problem. It contains the test results,
the instrument's identity and your browser version — and nothing else. It contains no
measurement, no personal data and nothing about you.
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

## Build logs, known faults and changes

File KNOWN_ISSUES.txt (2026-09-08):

KNOWN ISSUES IN THE RELEASED DATA -- EEG FIELD KIT, PACKAGE v2.4
TI One Voice research programme, one.witysk.org, Brussels, Belgium
2 September 2026.  Board revision B.

This file exists so that a manufacturer, a reviewer or a bidder finds the problems here
rather than at CAM time.  Everything below is also stated in the controlled documents; this
is the short list, in one place, of what is wrong with the data as shipped.

REWRITTEN ON 2 SEPTEMBER 2026, NOT PATCHED.  The text this file carried until that evening
was written against package v2.2 and was overtaken by the fixes of the same day faster than
it was edited: it still called the bias topology unfixable, still called S-02 open, still
listed as fileless a dozen parts that ship in mech/, and still quoted a segment census two
routing passes old.  A short list that contradicts itself is worse than no short list, so
every statement below was rebuilt from the files and from the tools' own output on the date
in this header.  Section 14 records what the file used to say and when each claim stopped
being true; the package convention is to correct a claim with its date, not to delete it.

NOTHING IN THIS PACKAGE HAS BEEN MANUFACTURED OR MEASURED.  No unit exists.  No board has
been fabricated, no part has been printed, no firmware has been flashed to silicon, and no
electrode has touched a person.  Every performance figure below is calculated or modelled,
and each one is labelled as calculated where it appears in the controlled documents.

--------------------------------------------------------------------------------------
0. THE FIGURES A REVIEWER SHOULD CHECK FIRST
--------------------------------------------------------------------------------------
All of these are the tools' own output on 2 September 2026 and can be re-run from tools/.

  BOARD, from tools/drc.py -> tools/drc_report.txt
    VIOLATIONS: 0 -- "none.  The board passes every rule listed above."
    145 of 145 routable nets are one connected copper island; 0 unclosed nets
    3 745 track segments, 552 through vias, 0 duplicate segments, 0 duplicate via positions
    min clearance   F.Cu 0.260   B.Cu 0.275   In1/In2 0.285   against a 0.200 mm rule
    narrowest track 0.200   smallest plated hole 0.300   copper to NPTH 2.00 mm
    zone crossings 0; exactly one AGND_REF-DGND bridge and one HARN_SHIELD-DGND bridge
    169 connections were routed at relaxed geometry (36 on a narrower conductor,
    133 at full width and a reduced gap).  Read section 2 before you order copper.

  FIRMWARE, from firmware/release/manifest.json
    ESP-IDF v5.2.5, target esp32s3, Phase 1 configuration (secure boot OFF, anti-rollback
    OFF).  Four images with their SHA-256: bootloader.bin 23,168 B; partition-table.bin
    3,072 B; ota_data_initial.bin 8,192 B; eeg_field_kit.bin 405,360 B.  The production
    simulation re-hashes all four on every run and prints the linked image as 405,245 bytes.

  TOOLS
    python3 tools/simulate_production.py    193 passed, 0 failed, 6 open
    sh webtest/tests/interop/run.sh         57 of 57 checks green
    python3 tools/check_consistency.py      0 banned figures in this file.  See below.

  check_consistency.py passed clean over the whole package when this rewrite began.  It does
  not now, and not because of anything here: the 2 September changes are still being written
  into the controlled documents, so the checker is currently reporting a stale simulation
  figure and a set of .docx/.pdf renditions older than their .md sources.  Re-run it.  If it
  names a line in THIS file, this file is wrong; today it names none.

THE SIX OPEN ITEMS the production simulation raises, and where each is treated below:
    static IRAM reports full, one byte free ................. section 3
    the v1 HM-01 mesh is two disconnected bodies ............ section 8
    no human layout engineer has reviewed the routing ....... section 2
    E-27 has never been seen to light ...................... section 5
    the two board-current figures cannot both be right ...... section 6
    SR-01 is closed in the design and not signed off ........ section 5

--------------------------------------------------------------------------------------
1. THE DRC GATE IS MET.  THE BOARD IS NOT YET RELEASED FOR FABRICATION.
--------------------------------------------------------------------------------------
ECO-EEG-016 section 3 sets the gate for releasing fabrication data as zero DRC violations,
every net one connected copper island, and both inner planes continuous under the analogue
zone.  ALL THREE ARE MET, on the census in section 0.

THE DATA IS RELEASED FOR REVIEW UNDER RFQ-EEG-002A.  FABRICATION RELEASE AWAITS THAT REVIEW.

That is a deliberate choice and not a formality.  Zero violations means the layout satisfies
the rules the programme wrote down.  It does not mean the layout is good.

--------------------------------------------------------------------------------------
2. THE ROUTING HAS NOT BEEN REVIEWED BY A HUMAN LAYOUT ENGINEER
--------------------------------------------------------------------------------------
It was produced by the programme's own constraint-aware autorouter.  Every clearance has
been measured on the finished polygons rather than on a routing grid, and the DRC report
lists every relaxed connection by name, so a reviewer can go straight to the places where
the router had to squeeze.  That is not the same as somebody having looked at it.

169 connections were relaxed -- 36 on a narrower conductor and 133 at full width with a
reduced gap -- against the 19 the earlier DRC report listed (ECO-EEG-016 C-12; the count
moves with the route).  Every one is at or above the 0.20 mm minimum conductor and the
0.20 mm minimum gap (0.35 mm on electrode nets), so nothing is illegal and no rule is bent.
But a board that closes at minimum geometry in many places is not the same board as one that
closes at preferred geometry: thin conductors run hotter and etch less reliably, and minimum
gaps are where a fabricator's yield problems appear first.  This is the first thing
RFQ-EEG-002A should look at.

WHAT THE PACKAGE'S OWN CHECKS CANNOT SEE.  tools/drc.py checks copper and has no silkscreen
rule.  A pin-1 legend tick on the wrong end of a package -- which is what the SOIC-14
footprint carried until 2 September, and which would have destroyed three op-amps at first
power-up -- was invisible to it.  The specific defect is fixed in tools/fplib.py and
tools/simulate_production.py now proves every pin-1 mark is nearest pad 1, but the general
point stands: silkscreen correctness rests on one targeted check, not on a rule set.

--------------------------------------------------------------------------------------
3. THE FIRMWARE IS BUILT AND HAS RUN IN AN EMULATOR.  NEVER ON HARDWARE.
--------------------------------------------------------------------------------------
Built against a real ESP-IDF v5.2.5 on 2 September 2026 (target esp32s3, Phase 1
configuration).  The four images the flash step needs are in firmware/release/ with a
manifest.json carrying their SHA-256, which the production simulation verifies on every run.

IT HAS RUN, UNDER QEMU.  firmware/release/qemu_boot.log is one full boot cycle captured
from qemu-system-xtensa 9.0.0 (-M esp32s3, -m 4M).  What ran: the second-stage bootloader
read THIS partition table -- all nine entries, including the calib and prov partitions --
and loaded the app from the factory slot at 0x20000; app_main() reached its banner; the
microSD mount failed and the firmware continued with the warning it was written to give; the
ES8388 codec failed and degraded the same way; and the 6 MiB ring buffer would not allocate,
where FW-D13's NULL guard caught it and named the cause.  Three bring-up paths exercised,
three behaved as designed.

WHAT THIS IS NOT.  An emulator is not a unit.  QEMU's esp32s3 has no octal PSRAM, no
microSD, no ES8388 and no ADS1299, so every peripheral this firmware talks to is absent.
Nothing has been flashed to hardware, nothing has enumerated over real USB, and no register
value, daisy-chain order or SPI timing has met silicon.  The run proves the image boots and
that the code paths which do not need peripherals behave as written.  It proves nothing
about whether the instrument works.  (sdkconfig.qemu sets CONFIG_SPIRAM_IGNORE_NOTFOUND to
get past the missing PSRAM.  That overlay is for emulation only and is not a build
configuration for any unit.)

AND THE RUN FOUND A FAILURE MODE WORTH FIXING, WHICH IS STILL OPEN.  Two subsystems degrade
and one aborts: a missing card and a missing codec are warnings, but missing PSRAM calls
abort(), and the unit then reboots into the same abort, forever.  On the bench that is
correct.  In a participant's home it is the worst available behaviour -- a boot loop is
indistinguishable from a flat battery or a broken cable, it never enumerates, and the browser
tool that exists precisely to answer "what is wrong with this unit" can never reach it.  A
unit that cannot record should still be able to SAY it cannot record.  Raised against F-06
and TOOL-EEG-022; the fix is to hold the fault, enumerate anyway, and report it through
CMD_IDENTIFY.  It is not made.

STATIC IRAM IS FULL, WITH ONE BYTE FREE.  firmware/release/size.json reports 16,383 bytes
used of 16,384 on the linked image.  If that is the real limit, the next function marked
IRAM_ATTR fails the link with an error naming a section and not a cause -- and this design
has more interrupt work coming (E-13's tone scheduler, E-12's onset detector).  Turning off
the SPI-slave and gptimer ISRs, neither of which this firmware uses, did not move the figure
by a single byte, so it is not those.  Either the pool is genuinely full, or esp_idf_size is
reporting against a fixed 16 kB window that is not the limit on an ESP32-S3 with octal
SPIRAM and XIP.  Reading the linker map against hardware settles it; guessing from here does
not.  It is open item 1 of the production simulation and FW-EEG-001 does not mention it.

--------------------------------------------------------------------------------------
4. THE CONNECTIVITY TEST PROGRAM HAS NEVER SEEN REAL HARDWARE
--------------------------------------------------------------------------------------
webtest/EEG-Connectivity-Test.html (TOOL-EEG-022) is written and its logic is tested.  The
protocol layer passes a unit test suite; the whole exchange passes against a simulated
device; and since 2 September the firmware and the tool are tested AGAINST EACH OTHER by
compiling the real main.c against ESP-IDF stubs and driving it with the real webtest
protocol module (sh webtest/tests/interop/run.sh, 57 checks, all green).  That harness
exists because the JavaScript-only tests passed throughout a period when the two sides
disagreed about the opcode byte, the acknowledgement layout and the capability bits: the JS
host and the JS simulated device were written by the same hand from the same specification
and shared one misunderstanding of it.  A cross-language check is what caught that.

None of it has run against a real unit, because no unit exists.

ONE THING IS STILL MISSING AROUND IT.  TST-EEG-004 section 12 requires the operator to
record the SHA-256 of the TOOL-EEG-022 file used at T30, and no reference hash is published
anywhere -- not in TOOL-EEG-022 section 2.1, not in T30's Record row.  The operator records
a hash with nothing to compare it against.  The built bundle itself is current: it is
rebuilt from source and is no longer the stale pre-2026-09-02 file that an earlier audit
found, which would have failed a good unit.

--------------------------------------------------------------------------------------
5. MET IN THE DESIGN.  NOT SIGNED OFF, NOT MEASURED.
--------------------------------------------------------------------------------------
Four things closed on 2 September 2026.  Each is closed in the design and none is approved
or measured, and those are different states that this package does not merge.

  S-02, SINGLE-FAULT PATIENT CURRENT, IS MET AT 36.8 uA against a 50 uA limit.
  ECO-EEG-024 is applied: R1-R16 are 68 kOhm, not 47 kOhm (tools/design.py:70-88).  It was
  53.2 uA, a 6.4 % overshoot on a SAFETY limit carried as not-met through three revisions.
  What it costs is written into the requirement it costs: E-10 states both branches and
  permits +/-1.0 dB for exactly this case, and the simulation confirms the 100 Hz response
  is inside it.  Same 0603 footprint, so the board did not move.  Normal-condition
  auxiliary current is 0.106 uA against a 10 uA limit.  NOT SIGNED OFF.  SR-01 is the
  electrical safety reviewer's finding, that reviewer owns its disposition, and the review
  has not started.  This is open item 6 of the simulation.

  THE BIAS-LEAD TOPOLOGY IS FIXED.  design.py's channel-11 exception is deleted: D11 and
  C11 now sit on BIASOUT, behind the series resistor, like the other fifteen channels
  (design.py:544-553).  Until that change the BAV99 clamp and the 10 nF filter on the
  driven bias lead to the Fpz forehead electrode sat on the PATIENT side, so a shorted D11
  half put a rail on the forehead electrode with no series resistor in the path at all --
  183.6 uA on this pack's bound B, unbounded on bound A -- and a shorted C11 bonded that
  electrode galvanically to AGND_REF.  RISK-EEG-011's SF-1a and SF-6a collapse into the
  ordinary SF-1 and SF-6.  Note that ECO-EEG-024 alone would NOT have fixed this: D11 had
  no resistor in its fault path, so a bigger resistor elsewhere changed nothing.  Getting
  it into the routed board cost a discarded full rebuild (63 of 145 nets) and three
  corrections to the surgical repair; tools/repair_nets.py re-runs the full DRC and
  refuses to write unless the board comes out at least as good as it went in.  It refused
  twice.

  E-27 IS MET IN THE FIRMWARE, AFTER A SECOND CORRECTION THE SAME DAY.  The bicolour phase
  driver is written.  It was first written to read both halves of the converter's lead-off
  word, LOFF_STATP and LOFF_STATN, with red as P AND N.  THAT COULD NEVER HAVE LIT RED.
  ads_init() enabled LOFF_SENSP only, so LOFF_STATN was zero on every channel for ever, the
  red term was always zero, and every site that had lost contact showed AMBER.  Enabling
  LOFF_SENSN was not the fix either: this board's montage is SINGLE-ENDED -- J2 carries IN1
  to IN8, one shared SRB1 and BIASOUT -- so there is no per-site negative electrode, and
  with SRB1 closed all eight N bits would have reported the one shared reference.

  FW-D17 replaced it with what the hardware does support: the positive-side comparator is
  read at TWO thresholds, COMP_TH swept between a sensitive and an insensitive setting.  Per
  site: trips neither = GREEN, trips the sensitive one only = AMBER, trips both = RED; green
  lit in phase A, red in phase B, amber in both.  The insensitive set is a subset of the
  sensitive one, so the three states are exhaustive and cannot overlap.  The alternation
  quantises to the FreeRTOS tick -- 2 ms half-phases on a 1 kHz tick, so about 250 Hz rather
  than exactly 240 -- which meets the "above 100 Hz" the requirement is written against, and
  is stated rather than rounded away.

  How it was missed and what now catches it: every check in the package asked whether the
  driver EXISTED, and it did.  simulate_production.py now resolves the colour expressions
  through their local aliases and fails if any colour depends on state ads_init() never
  enables; that check fails against the pre-FW-D17 source and passes against this one.  The
  first version of the check did NOT resolve aliases, found no g_loff_* names in `p & n`
  and passed the very defect it was written for -- which is the same lesson twice in one
  file.

  NEVER SEEN TO LIGHT.  No unit exists, so no light has been driven, and T11 -- which reads
  the R/G ratio with a colorimeter -- has not been run.  AND THE COLOUR BOUNDARIES ARE NOT
  SET: the two COMP_TH values are the ADS1299's documented endpoints, not measured trip
  points, so the impedance at which a site turns amber, and the one at which it turns red,
  are unknown until a unit is characterised.  T11's reference resistances are provisional
  until then.  Simulation open item 4.

  CMD_LIGHTS ANSWERS HONESTLY NOW (FW-D18).  The handler took c[1] as a plain enable and
  answered 0x00 OK to every value, so a host asking for mode 3 (force red) was told the
  request had succeeded while the firmware carried on showing automatic colour.  Modes 2, 3
  and 4 are implemented -- force green, force red, force amber, with an optional site mask
  in c[2] -- a mode the firmware does not have is refused with 0x0B UNIMPLEMENTED, and a
  payload with no mode byte is refused with 0x02 BAD_LENGTH.  Eight interop checks cover it;
  the harness compiles the real main.c, so they are checks and not restatements.

  E-11 IS MET, IN BOTH HALVES.  The Sallen-Key moves from X7R to C0G.  X7R is +/-15 % over
  temperature and f0 goes as 1/sqrt(C1.C2), so the corner ranged over 42.4 to 57.4 Hz
  against a 45 to 55 band: no build could hold it.  The obstacle was that 100 nF C0G is
  not a stocked 0603 part, so the network stopped asking for 100 nF -- capacitors down by
  ten, resistors up by ten: 10 nF and 22 nF C0G with 215 kOhm, f0 = 49.9 Hz, Q unchanged
  at 0.742, corner 47.5 to 52.5 Hz at C0G's +/-5 %.  The 10 nF is the same part the board
  already buys sixteen of as the electrode filter C1-C16, so it adds no purchasing line,
  and the footprints and nets are unchanged, so the board did not move.  NOT MEASURED:
  T12e reads it on a built unit.

TWO MECHANICAL FITS ARE IN THE SAME STATE -- measured on the solids, never printed.

  THE HM-04 / HM-05B SERVICE BAYONET ASSEMBLES AND TURNS.  Until 2 September the released
  meshes could not: the carrier's lug outer radius was 5.40 mm into a 5.30 mm slot,
  tangential clearance was zero in a material printed to +/-0.15 mm, and HM-04 had two
  straight axial slots and no circumferential run to turn into.  It is invisible from the
  key side, which is why nobody caught it -- HM-09's service key lugs are narrower and did
  fit, so the key worked on a joint the carrier could not use.  The re-cut is in
  tools/mech_gen.py: HM-05B's lug is 1.40 mm wide, 0.65 mm proud at r 4.55, outer radius
  5.20 mm, raised to z 1.20..3.30; HM-04 has 1.70 mm entry slots at outer radius 5.55, a
  100 degree circumferential run at z 1.10..3.80, and 1.10 mm of solid material below it
  as the retaining lip. tools/simulate_production.py intersects the two solids at four
  rotations and three axial positions on every run: no interference through the quarter
  turn, none through the carrier's 0.40 mm of spring travel, and measurable lip engagement
  when a seated carrier is pulled down -- the number that says an inverted helmet keeps
  its electrodes.  Reinstating the original lug centre makes that check fail, so it does
  not pass by accident.  NOT CLOSED BY THIS.  An intersection volume of zero says two
  solids do not overlap, not that PA12 at +/-0.15 mm turns by hand; the FIT-01 coupon
  remains the acceptance and none has been printed.  The cup pocket is still sized by what
  is left rather than by a cup, because HM-05A is a bought-in sintered cup "modified for
  the service bayonet" and the modification has never been drawn.  The cup contact crown
  and leaf are ASM-EEG-023's cannot-decide-here.

  THE FRAME NOW CARRIES ITS OWN HARNESS, IN THREE PARTS.  WH-EEG-008 section 7 gives every
  frame run two channels -- A on the outer wall for the electrode cable, B on the
  skull-facing wall for the light cable, 3.80 mm bore at 6.00 mm centres inside 1.20 mm
  walls, which needs a 12.20 mm section.  The carried-over HM-01 mesh has ONE bore per run
  in a 10.91 mm band: one channel where two are specified, and too narrow to hold the pair
  even if a second were cut.  That matters because the 6.00 mm of separation IS the
  ECO-EEG-014 rule keeping the light group away from the electrode group, and E-30 is
  written against it; a frame with one channel means both cables in one bore, the single
  arrangement the harness document forbids.  HM-01P-A, -B and -C now draw the halo,
  sagittal and coronal runs parametrically with the section the harness needs, and the
  simulation probes across the band for material on every run: 1.20 mm wall, 3.80 mm
  channel A, 2.20 mm centre web, 3.80 mm channel B, 1.20 mm wall, with channel centres 6.0
  mm apart.  THREE PARTS, NOT ONE, and honestly so: unioned into a single frame they came
  out as two disconnected bodies, because the three centrelines were each fitted
  independently to the v1 mesh and nothing ever required them to meet.  Joining them needs
  the head surface between them, which is exactly what the Stage 0 fit measurement holds
  -- and that measurement has not been taken, so the head-shape surfaces, the pad seats
  and the electrode site normals still come from the v1 study and will move when it is.
  This is a channel correction, not an ergonomic re-design.

AND ONE LIMIT EXISTS WITH NO MEASUREMENT BEHIND IT.  WH-EEG-008 justified leaving the
contact-light cable unscreened by asserting the lights are dark during recording blocks.
E-27 contradicts that: the lights are driven FROM the converter's own lead-off measurement,
so a lit light means a live measurement on the same electrode by definition.  The concurrent
case is electrode preparation -- the participant gelling a site and watching its light --
which is the state the lights exist for, and where the two conductors are closest.  The
design's controls are real and unchanged (two occipital entries, channels A and B at 6 mm
centres, an LED_GND guard conductor down the middle of the bundle, J30 in the digital zone,
source impedance below 1.1 kOhm).  What was missing was a limit and a measurement.
RFQ-EEG-001 E-30 now states the limit -- added noise below 0.5 uV RMS in 0.5-70 Hz, half what
E-03 allows the channel in the same band -- and TST-EEG-004 T9c measures it through the fitted
harness in an assembled helmet.  NEITHER HAS BEEN RUN.  Until T9c runs on a built unit, the
decision to leave WH-02 unscreened rests on an argument.
The same coupling problem exists at the site, and got the same answer: hm04() used to cut the
contact-light window as one box straight through the body, so the "inboard" and "outboard"
openings were two ends of a single cavity and any scheme putting the electrode conductor in
one end and the switched LED in the other had them sharing open volume about 3 mm apart at all
eight sites -- which is RISK-EEG-011 SF-9 exactly.  It is now two pockets with 1.60 mm of
printed PA12 between them.  Separated by material, not by distance, and also not yet measured.

--------------------------------------------------------------------------------------
6. REQUIREMENTS THAT ARE NOT MET
--------------------------------------------------------------------------------------
  * E-23's 45 C charge inhibit, and S-04's thermistor-monitored charging.  There is no NTC
    net in design.py and no thermistor way on J12 or J13, so nothing in this design measures
    cell temperature.  No module choice closes this.  E-23's other half -- thermal regulation
    in the charger IC -- is met on the module.  The two hardware holes are the same hole, no
    closure is proposed, and neither half can be tested.

  * The two board-current figures do not reconcile.  TST-EEG-004 T3 limits J13 to 150 mA
    while ICD-EEG-006 section 2.7 tallies about 440 mA.  E-22 is met either way -- 20.0 h of
    recording against 6.8 h -- but the charger, the thermal budget and T3's own limits rest
    on the number.  It is measured, not calculated, at T3.  Simulation open item 5.

--------------------------------------------------------------------------------------
7. PARTS THAT ARE NOT SETTLED
--------------------------------------------------------------------------------------
  * The boom-microphone preamplifier at J21.  RFQ E-14 forbids automatic gain control, so
    package v1's MAX9814 is NOT approved -- it is an AGC part and disabling its AGC is a
    module-dependent modification.  The socket is specified by its interface in ICD-EEG-006.
  * The room-microphone module with hardware mute (E-15) has no qualified part.  No catalogue
    module is yet known to meet it; the fallback is a programme-designed sub-assembly.
  * J15-J17, the touch-proof DIN 42802 sockets, name a class and not a part.  AVL-EEG-017
    calls this the highest-risk line in the file: no qualified vendor at all, on a Class A
    patient-contact part, with an assumed 12-week first-article lead time.
  * USB VID/PID are placeholders; the pid.codes application is not made.
  * Supplier parts are still unnamed for HM-03C, HM-05A, HM-06C, HM-07B, HM-07C, POD-P1-03
    and CASE-01 (PARTS-EEG-019 OA-7).

--------------------------------------------------------------------------------------
8. GEOMETRY: WHAT NOW EXISTS, AND WHAT STILL DOES NOT
--------------------------------------------------------------------------------------
Twelve printed parts that had no files now have STL, STEP, a MECH-EEG-020 sheet and a row in
mech/MANIFEST.json, and AVL-EEG-017 K24 names them so a print bureau can quote them:
HM-02B, HM-02C, HM-03A, HM-05B, HM-10, HM-11A/B/C, POD-P1-04 and WH-ADP-02/-03/-04, together
with all three WH-KEY-01 shroud forms.  HM-12 and the three HM-01P channel runs ship too, and
WH-BUS-01 has a full fabrication data set in kicad/wh-bus-01/.  mech/MECH_RELEASE_STATUS.md
is the generated list of what tools/mech_gen.py actually writes.  NOTHING HAS BEEN PRINTED.

WHAT IS STILL ABSENT, and deliberately so -- a part that is the wrong shape is worse than a
part that is honestly absent:
  * HM-03B, the ratchet dial housing, because HM-03C has no vendor, outline, spindle or
    fixing pattern.
  * HM-06A and HM-06B, the chin cup and its liner: the package fixes the 20 mm webbing and
    the 200 N anchor pull and nothing at all about the shell.
  * HM-07A, the boom temple mount, for a gooseneck with no vendor and no diameter.
  * The Phase 2 occipital shell (M-01).  The Rev B carrier is 150 x 130 mm, no split design
    has been drawn, and nothing in the Phase 2 enclosure line can be quoted or built today.

HM-01 EXISTS AS AN STL AND HAS NO STEP.  It is a carried-over form study with no parametric
source (PARTS-EEG-019 OA-1), and the production simulation measures a second problem in it:
the mesh is watertight, which MANIFEST.json records, and it is TWO DISCONNECTED BODIES, which
nothing recorded.  A frame that is two shells is one more reason the OA-1 redraw has to
happen.  Simulation open item 2.

--------------------------------------------------------------------------------------
9. ECO-EEG-023 IS SPECIFIED AND IS NOT IN THE DATA
--------------------------------------------------------------------------------------
The comparator U7 is powered from AVDD and AVSS in the released netlist (design.py:596-597),
and its 52 mV threshold is derived from AVDD.  ECO-EEG-023 would re-power it from
DVDD3V3/DGND and re-reference its inputs, which changes that threshold.

It is deliberately NOT cut in, and ECO-EEG-016 carries it as "OPEN, not implemented".  The
safety and layout reviewer must see it before it is applied; implementing it silently would
defeat the review.

--------------------------------------------------------------------------------------
10. THE .kicad_pcb ZONES SHIP UNFILLED, ON PURPOSE
--------------------------------------------------------------------------------------
kicad/EEG-CAR-01_RevB_routed.kicad_pcb carries the zone OUTLINES and the mounting-hole
keep-outs, but no filled_polygon cache.  A KiCad fill cache is one simple ring per island and
cannot express a hole; each inner-plane Gerber carries 698 clear-polarity void regions, so a
cache would have to be a solid rectangle -- which is what an earlier revision of the writer
shipped.  The DRC counts 4 pour islands in all, one continuous island per net per plane.

Press "Fill all zones" when you open the board.  The AUTHORITY for copper is kicad/gerber/,
which uses LPD/LPC polarity and carries every void.

--------------------------------------------------------------------------------------
11. WHAT A MANUFACTURER STILL CANNOT DO FROM THIS PACKAGE
--------------------------------------------------------------------------------------
On 2 September 2026 the package was audited stage by stage against one question: could a
competent contract manufacturer, given ONLY these files and no access to the authors, execute
the stage and hand on a correct result?  The answer was no, at every one of the six stages,
and the audit found thirty-two specific things that could not be done.

TWENTY-EIGHT OF THE THIRTY-TWO WERE CLOSED by writing the missing files -- ASM-EEG-023 Rev B
is the record.  What was written: the stencil aperture table, the IPC-D-356A netlist, the lot
coupon and lot documents, the ATECC608B configuration template and the provisioning
safeguards, a working provision.py --dry-run, the calibration schema and its worked example,
the per-unit record schema with an example record and a lot-summary template (records/), the
fixture PCB artwork and printed geometry and RP2040 firmware with passing host tests
(fixtures/), the FIX-02/D attenuator derived to E96 values, the label and packaging artwork
set (graphics/labels/), the HM-12 umbilical entry plate, the harness bus board, and the
mechanical release register.  The webtest deliverable was rebuilt from source, and the
TST-EEG-004 renditions now carry T30.

THE REMAINDER ARE NOT MISSING FILES.  They are missing DECISIONS, and section 12 is where
they live.  Two of them are not engineering questions at all and no amount of work in this
package closes them:

  * THE PROGRAMME'S OWN POSTAL ADDRESS AND TELEPHONE NUMBER appear in no file here.
    ART-LBL-03, ART-LBL-05, ART-LBL-06 and ART-RET-01 are drawn, dimensioned and complete
    apart from <<PLACEHOLDER>> fields for them, and the generator will not invent them.  Four
    of the eleven artwork files therefore cannot be printed.  A dead telephone number on a
    regulated mark, or an unaddressed return label on a case base, is a kit that does not
    come back.
  * THE REGULATED LITHIUM-BATTERY PICTOGRAM of ART-LBL-06.  The battery-group-and-flame mark
    belongs to the edition of ADR / IATA DGR in force, this package does not hold it, and
    REG-EEG-012 section 3.7 makes the DG-trained shipper the person who completes and
    approves that mark.  A programme may not draw it for itself.

THE PACKAGE IS NOT YET A COMPLETE MANUFACTURING RELEASE, and RFQ-EEG-001 should not be read
as though it were.  A bidder pricing "the whole thing" from these files is pricing an
unknown, and section 1.1a of that document asks bidders to say so.

--------------------------------------------------------------------------------------
12. TWENTY-TWO ASSUMPTIONS, DECIDED AND WRITTEN DOWN.  NONE APPROVED.
--------------------------------------------------------------------------------------
Twenty-two questions were decisions rather than files: a threshold voltage nobody had fixed,
a fastener nobody had chosen, a termination method nobody had drawn.  They are in
docs/ASM-EEG-023 Rev B, one entry each -- 8 derived, 11 judgement, 3 that cannot be decided
from what exists.  TEN BLOCK A BUILD.

Each was decided, then attacked by an independent reviewer, then re-decided against the
attack.  NOT ONE OF THE TWENTY-TWO SURVIVED THE ATTACK UNCHANGED, which is the most useful
thing to know about them.  Attacks were themselves checked before being conceded to, and
several were partly refuted on the files; those are recorded as kept.

ALL TWENTY-TWO REQUIRE A HUMAN SIGN-OFF and none is approved by that document.  A decision
with its reasoning attached is worth having because a reviewer reads a proposal faster than a
blank page, and because it makes an assumption visible instead of leaving it to be found by a
manufacturer at the point where it costs money.  It is not an approval, and this programme
does not confuse the two.

--------------------------------------------------------------------------------------
13. NOTHING GOES ON A PARTICIPANT'S HEAD
--------------------------------------------------------------------------------------
The electrical safety review has not been done.  It gates Phase 2 and it gates any use on a
person.  It does not gate manufacture.  S-02 being met in the design (section 5) does not
change this by one line: SR-01 is the reviewer's finding and is open for their disposition.

--------------------------------------------------------------------------------------
14. WHAT THIS FILE SAID BEFORE, AND WHEN IT STOPPED BEING TRUE
--------------------------------------------------------------------------------------
Corrected here on 2 September 2026 rather than deleted, so that a reader holding an earlier
copy can see which claim moved and why.

  "PACKAGE v2.2" in the header.  Wrong since this package became v2.4.  Corrected.

  "The bias electrode is the one patient conductor whose clamp is not behind a resistor...
  NO LAYOUT CHANGE ALTERS THIS."  True until 2 September 2026, when design.py's channel-11
  exception was deleted and the routed board was repaired to match.  D11 and C11 are on
  BIASOUT.  SF-1a's 183.6 uA and its unbounded bound-A case are withdrawn.  See section 5.

  "S-02, single-fault patient current: 53.2 uA against a 50 uA limit, with the 47 kOhm
  series resistors fitted... That is a Phase 1 decision and it is open."  Superseded 2
  September 2026: ECO-EEG-024 is applied, R1-R16 are 68 kOhm, and the figure is 36.8 uA.
  S-02 is met in the design and unmeasured and unsigned.  See section 5.

  "The 240 Hz alternation it is written against does not yet happen -- the same firmware
  gap that stops T11 passing."  Superseded 2 September 2026: the phase driver is written,
  T11 can pass, and the alternation is about 250 Hz because it quantises to the FreeRTOS
  tick.  The rest of that paragraph -- that E-30 and T9c have never been run -- is still
  true and is carried in section 5.

  "Segment count 3 560 -> 3 744; via count unchanged."  That census predates the bias
  repair.  The final board is 3 745 segments and 552 vias.  See section 0.

  "The harness runs 38 checks green."  Withdrawn twice: the harness ran 49 when that
  correction was written, and runs 57 since the eight CMD_LIGHTS checks of FW-D18.
  See section 4.  check_consistency.py now holds every document to one figure for it.

  "TWENTY-FOUR OF THE THIRTY-TWO ARE NOW CLOSED", followed by a thirty-item remainder
  list.  Both were wrong together: the count was one pass behind and the list was the
  original audit output, so it named items the same section called closed.  ASM-EEG-023
  Rev B records twenty-eight of thirty-two closed, and section 11 above states what is
  left without re-printing a list that another document owns.

  "Several sub-assemblies named in the packing list have no files at all: HM-03A/B/C,
  HM-06A/B/C, HM-10, HM-05B, HM-11A/B/C, POD-P1-03/04/05, WH-KEY-01, WH-BUS-01, WH-ADP-01
  to -04."  Superseded 2 September 2026 for twelve of those parts, which ship in mech/ and
  are named in AVL-EEG-017 K24.  Section 8 lists what is genuinely still absent.  This
  file's section 8 is named in mech/MECH_RELEASE_STATUS.md as one of the documents that
  had to be corrected against the directory; it now is.

  "webtest/EEG-Connectivity-Test.html is a stale build... The shipped file FAILS a good
  unit."  True of the pre-2026-09-02 bundle.  The deliverable has been rebuilt from
  source.  What remains open is narrower and is stated in section 4: no reference SHA-256
  is published for the operator to check theirs against.

--------------------------------------------------------------------------------------
HOW THIS LIST IS KEPT HONEST
--------------------------------------------------------------------------------------
  python3 tools/check_consistency.py     refuses superseded figures and names, and checks
                                         that the figures which must agree across the
                                         package do agree.  It exits non-zero on a finding.
                                         Findings are open against other documents today;
                                         none against this file.  See section 0.
  python3 tools/simulate_production.py   walks a unit through all fifteen stations and
                                         checks the package supports each step.
                                         193 passed, 0 failed, 6 open.  The six are
                                         listed in section 0.
  sh webtest/tests/interop/run.sh        compiles the real firmware main.c against stubs
                                         and drives it with the real browser-tool
                                         protocol code.  57 checks, 0 failed.
  The DRC's own uniqueness check         catches duplicate copper, which is how twenty-
                                         eight duplicate segments and four doubly-drilled
                                         via positions reached the Rev B data before v2.1.

A tool that agrees with the documents is not evidence.  Everything in this file that says
"met" means met in a calculation or in a model, and every one of those still needs a bench.

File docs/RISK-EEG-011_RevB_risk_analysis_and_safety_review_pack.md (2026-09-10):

# RISK ANALYSIS AND SAFETY REVIEW PACK

**Document:** RISK-EEG-011  **Revision:** B  **Date:** 2026-09-01
**Issued by:** TI One Voice research programme (one.witysk.org), Brussels, Belgium
**Licence:** CC BY-SA 4.0
**Governing documents:** DSN-EEG-003 Rev D, then RFQ-EEG-001 Rev E. Where this document and
design.py disagree, design.py governs.

**Why this document exists**

RFQ-EEG-001 section 9.2 makes an electrical safety review the gate between two prototypes and
ten kits worn by human participants, and DSN-EEG-003 Rev D section 8 records that no safety
engineer has reviewed any of this design. Until now that gate had no input document and no
form: there was no hazard analysis, no patient auxiliary current calculation, no isolation
report, no checklist and nothing to sign. This pack is that input. It analyses the instrument
as an ISO 14971-style risk file, works the S-02 current budget through with the real parts of
EEG-CAR-01 Rev B, states what the isolation barrier is and where it lives, sets out battery
safety for a kit that travels by post, and ends with the checklist, acceptance criteria and
signature block the reviewer works to. It is written on the assumption the reviewer is a
stranger to the programme and hostile to hand-waving. **Nothing in this package has been
built, and no safety engineer has reviewed this design.** Nothing in it has been measured.
Every figure marked *calculated* is exactly that, and the review's first job is to decide
whether a calculation is enough evidence for the decision it supports.

**What changed in Rev B.** Two things about the carrier changed during layout and they change
parts of this pack. The board grew from 130 × 124 mm to **150.0 × 130.0 mm**, because thirty
connectors, 211 parts and 156 nets would not close at the smaller size. The board went from
two layers to **four** -- L1 signal, L2 reference plane, L3 reference plane, L4 signal --
because a two-layer carrier cannot be both a continuous reference under every analogue trace
and a second routing surface at the same time. Package v1 asserted that two layers would be
enough; doing the layout showed that it is not. Section 5 explains what four layers means for
the isolation argument, and it is more work to verify, not less: the keep-out under the
barrier must now be proved on four copper layers, two of which are invisible from the outside
of a finished board. Section 5.5 records what the design rule check now says about both halves
of that: the isolation rule area is clean on all four layers, and the report now records zero
violations of any rule, with all 145 nets connected. The fabrication data is **released for
review** under RFQ-EEG-002A. It is not released for fabrication: the routing was produced by
the programme's own tools and no human layout engineer has read it.

**Corrections within Rev B (2026-09-01).** The findings of the second cross-document audit that
name this pack are closed in this issue, within the same release and without a revision letter
change. They were the DRC state and its place as a release gate (section 5.5, SR-11, checklist
item 4.16), the isolation-strip claim, which is now made because the DRC report records it
rather than because a rule area was drawn, and E-10, whose two states are now stated together
everywhere the requirement appears. The binding answers are in **RUL-EEG-021 Rev B**, the
rulings register, sections A, B and C; where this pack and `tools/design.py` disagree,
design.py governs.

**Corrections within Rev B (2026-09-02), after the design changes of 2 September 2026.** Four
changes were made in the source today and all four reach this pack, so each is written up
where the pack already analyses the thing it changes. **Channel 11 is no longer an exception.**
The override in `tools/design.py` that put `D11.3` and `C11.1` on `BIAS_EL`, the patient side of
R11, is deleted; the row is now generated by the same loop as the other fifteen, so the clamp
and the filter sit on `BIASOUT`, behind the series protection resistor, like the other fifteen.
SF-1a and SF-6a of section 4.4 are closed by that change and are restated below with the ordinary
SF-1 figures. Those figures moved again the same day, when ECO-EEG-024 was applied: they are
**36.8 µA bound A and 30.0 µA bound B** at the 68 kΩ now fitted, and the 53.2 µA / 41.2 µA this
paragraph carried at first issue are superseded from 2026-09-02 (see the ECO-EEG-024 paragraph
below). The 183.6 µA that SF-1a carried is withdrawn. **SR-12 is closed in the design and its
disposition is still owed**, because applying the fix an analysis points to is not the same as
having the reviewer who owns the finding approve it. **The HM-04 contact-light window is now two
pockets** with 1.60 mm of printed PA12 between them -- an outboard LED seat and an inboard
conductor run -- where it was one box straight through the body. That materially reduces SF-9
and strengthens the basis of H-05, and it does not eliminate either: nothing has been printed,
and SF-9's own control is physical separation *and its verification*, of which only the
separation half has moved. **HM-04's spring seat is deepened** from 4.50 to 6.60 mm, which takes
the free height above the carrier's spigot from 1.40 mm to 3.50 mm; that is written up at H-17,
whose control is a 3--6 N spring that could not have been bought in the volume the released
geometry left for it and that is still unspecified. **E-27's bicolour phase driver is written**, so the sentence H-25
carried, that the driver was specified and not yet coded, is superseded on this date. Nothing in
this package has been built or measured; the mechanical figures quoted below and in
PARTS-EEG-019 are booleans and dimensions taken from solid models, not from parts. One consequence reached the routing, and it has since been
worked through. **Corrected 2026-09-02:** at first issue this paragraph said the carrier *was being
re-routed* for the channel 11 change, because moving `D11.3` and `C11.1` swaps R11's pads and
changes the `BIAS_EL` and `BIASOUT` nets. That re-route is done. `kicad/EEG-CAR-01_RevB_DRC_report.txt`
of 2026-09-02 reports **145 of 145 nets fully connected, VIOLATIONS: 0, 3 745 track segments and
552 vias**, with the isolation rule area clean on all four copper layers and the 0.35 mm electrode
clearance met, so every statement in section 5.5, in section 7 and in SR-11 that rests on the
design-rule report now rests on the post-change report and not on a superseded one. Two things are
recorded rather than assumed. The router still had to relax **169 connections** to close, which is
the figure those sections already carry. And the relaxed-geometry connection the report lists twice
as "BIASOUT J2.10 -> R11.1", at 0.20 mm track and 0.35 mm gap, was **expected to retire with the
change and did not**: it is still listed, at the same geometry, in the post-change report. The
expectation is withdrawn; the connection is one of the 169 the RFQ-EEG-002A reviewer is asked to
look at.

**Corrections within Rev B (2026-09-02), after ECO-EEG-024 was applied.** On the same day, and
after the bias-topology change above, the programme took **disposition 2 of section 4.5**:
`tools/design.py:88` now fits **R1--R16 = 68 kΩ 0.1 % 25 ppm thin film** (Vishay
TNPW060368K0BEEA) in place of 47 kΩ, in the same 0603 footprint, on the same nets, so sixteen
parts change and the board does not move. Every single-fault figure in section 4 moves with them:
**bound A from 53.2 µA to 36.8 µA, bound B from 41.2 µA to 30.0 µA**, against S-02's 50 µA limit.
**S-02 is therefore met in the design from 2026-09-02**, on bound A, which is the bound this pack
judges against and the worse of the two. The 53.2 µA and 41.2 µA figures are superseded as
statements of the live design and are kept below only where this pack records what it corrected.
E-10 moves with the resistors onto its **±1.0 dB** branch, which the requirement already states
and which is earned by exactly this change and by nothing else; TST-EEG-004 T22 grades against it.

**SR-01 is not closed by this, and this pack does not close it.** The finding belongs to the
electrical safety reviewer of section 7, the review has not started, nothing in this package has
been built or measured, and a programme applying the fix its own analysis recommended is not the
same as the reviewer who owns the finding accepting it. What the change alters is the question the
reviewer is asked: they are now handed a design that **meets** the limit by calculation and asked
to confirm it, rather than one that does not and asked to accept it. Section 10 keeps SR-01 open,
and section 7.3 item 4.3 is the form it is disposed of on.

---

## 1. Intended use, users, use environment

### 1.1 Intended use

The EEG field kit is a sixteen-channel research instrument that records scalp EEG, facial and
laryngeal EMG, and three audio envelope channels, together with button responses and audio,
during a scripted listening and speaking protocol. It streams that data over an isolated USB
link to a browser-based session runner and writes an identical copy to a microSD card.

It exists to produce group-level data for one pre-registered study. It performs no analysis on
the device, applies no algorithm to a participant's data in real time, and returns no result of
any kind to the person wearing it.

### 1.2 This is not a medical device

The instrument has no diagnostic, therapeutic, monitoring, prognostic or screening purpose. It
is not placed on the market. It is loaned, not sold. It is not a medical device within
Regulation (EU) 2017/745, and the programme makes no claim that it is one. REG-EEG-012
carries the declaration, the reasoning and the controlled wording; M-03 puts the sentence
"research instrument -- not a medical device" on every enclosure label.

The design nonetheless follows the applicable principles of IEC 60601-1 for a type BF applied
part. Those two statements are not in tension and the reviewer should not read them as such:
the programme designs to a medical-electrical standard because the device touches a person for
two hours at a time, and claims no certification because it has no medical purpose and is not
being sold. Where this pack cites IEC 60601-1 it cites it as a design reference, not as a
conformity claim.

The word *patient* appears in this document only inside the standard's own term "patient
auxiliary current". Everywhere else the person wearing the instrument is a **participant**.

### 1.3 Users

| User | Who they are | What they do | Training |
|---|---|---|---|
| Participant | An adult who has consented to the study and reports voice-to-skull experiences. Not a clinician. Alone in their own home | Unpacks the kit, applies paste, puts the helmet on, follows the on-screen runner, presses buttons, ends the session, repacks and posts the kit back | A laminated card (IFU-EEG-014), an on-screen guide, and a support telephone number. No supervision, no site visit |
| Operator | Programme staff at Brussels | Refurbishes returning kits, replaces consumables and electrode cups with the HM-09 service key, runs the incoming test subset, despatches | Trained on SVC-EEG-013 |
| Manufacturer | The contract manufacturer | Builds, provisions, tests to TST-EEG-004 Rev C, packs | IPC-A-610 class 2, plus this pack for the risk-control components |
| Safety reviewer | An external engineer engaged by the programme | Section 7 of this document | See 7.1 |

### 1.4 Use environment

A domestic room. Uncontrolled temperature (assume 15 to 35 °C), uncontrolled humidity, mains
sockets of unknown quality, a mains-powered laptop of unknown make on the same desk, pets,
children, furniture, and no one else present. The kit travels between uses by courier in a
hard case, is handled by carriers who do not know what is inside, and is unpacked by someone
who has never seen it before.

Sessions are two to three per participant, each about two hours, of which up to two hours is
with the helmet on the head and headphones on the ears. A kit serves about twenty
participants a year in sequence, and more than that over the fleet's life; the arithmetic is
SVC-EEG-013 section 2, which costs fourteen days with a participant and about twenty
turnarounds per kit per year. The occurrence scores in section 3 are written against the
annual figure, and a multi-year fleet raises the exposed population above it.

### 1.5 Reasonably foreseeable misuse

Charging while wearing the helmet. Opening the battery hatch. Wearing it while cooking,
driving, or lying down. Wearing it overnight. Substituting other headphones. Letting a child
or another adult wear it. Immersing the helmet in water to clean it. Using the recording as
evidence of an external attack, and being distressed when told it is not.

---

## 2. Hazard identification

Hazards are grouped by energy or agent. Each group ends with the design property that is
supposed to hold it, so the reviewer can attack the property rather than the prose.

**Electrical.** The only mains-referenced conductor anywhere in the system is on the host side
of the ADuM4160 module at J10. The carrier has no host-side copper at all: J10's four pins are
VDD_ISO, USB_DN, USB_DP and DGND, all device-side (verified against design.py). The host
connection is a socket and not a captive cable -- the isolator module's own host receptacle,
USB-B on the only named candidate and brought to a panel USB-C by the WH-09 pigtail, which is
a live non-conformance against E-24 (section 5.4), presented through a gasketed aperture in
POD-P1 -- so exactly one externally accessible data connector exists on the pod. Everything
on the participant's side of the
barrier is a floating island powered by one 18650 cell. The credible electrical hazards are
therefore (a) failure of that barrier with a mains-referenced host attached; (b) a conductive
path that bypasses the barrier altogether -- specifically the ESP32-S3-DevKitC-1's own two
USB-C receptacles, which sit on GPIO19/20, the same pins the carrier taps for J10, and are on
the non-isolated side; (c) a fault putting an internal rail on an electrode; (d) the charge
input at J24, which is fed from a consumer mains adaptor whose isolation the programme does
not control.

**Thermal.** About 0.6 W dissipated inside a printed enclosure worn against the occiput, and
about 1.2 W while charging. Cell abuse is covered under battery.

**Mechanical.** A 1 m drop of a packed case. The chin strap. The 1.2 m headphone cable. The
printed bayonets and the frame edges. Pressure from eight spring-loaded electrode assemblies
over two hours. A crushed cell after a drop.

**Chemical.** Conductive paste and abrasive prep gel applied by an untrained person to their
own scalp, near their own eyes. 70 % IPA, which is an operator agent at refurbishment and is
deliberately not in the participant kit. Biocompatibility of the skin-contact materials listed
in REG-EEG-012 §6.2, none of which currently has a declaration on file. That list is eight
rows, this pack counts the same eight, and SR-05 is written against every row on it.

**Biological.** About twenty people a year, and more over the fleet's life, wear the same
frame, the same ear clips, the same boom and the same ear cushions in sequence, with paste
and abraded skin in the loop.

**Information.** A microSD card holding raw EEG, the participant's voice and room audio
travels back through the post. A unit can be confused with another unit, or its calibration
record attached to the wrong serial, which corrupts data rather than injuring anyone -- but the
study is the reason the device exists, so a data hazard is a real hazard.

**Psychological.** This cohort has been recruited because they report being acted on and
controlled by others at a distance. A strap under the chin, eight lights on the head, a
microphone pointing at the room and a device described as "recording your brain" are not
neutral objects to them. A red light, a failed session, a device that will not connect, or an
instrument that appears to switch itself on can be incorporated into a persecutory belief, at
home, at night, with no clinician within reach. This is not a soft category appended for
completeness; on this programme it is the hazard with the highest expected frequency.

---

## 3. Risk table

**Severity.** S1 negligible (no injury, momentary discomfort) · S2 minor (reversible, no
intervention) · S3 serious (reversible, needs intervention) · S4 critical (irreversible
impairment) · S5 catastrophic (death).

**Probability**, per participant-session. The whole programme is about 3,000
participant-sessions at 50 kits, so P1 means "not expected to happen once in the programme".
P1 improbable (< 1e-5) · P2 remote (1e-4 to 1e-5) · P3 occasional (1e-3 to 1e-4) · P4 probable
(1e-2 to 1e-3) · P5 frequent (> 1e-2).

**Risk index** R = S × P. **1--4** acceptable · **5--9** acceptable with the control in place
and the residual stated to the participant · **10--14** tolerable only on the reviewer's
written acceptance · **15--25** unacceptable, must be reduced before use on a person.

Probabilities are engineering estimates by the programme, not field data. There is no field
data. The reviewer may reject any of them.

| ID | Hazard | Sequence of events | Harm | S | P | R | Control | Verification | Residual S/P/R |
|---|---|---|---|---|---|---|---|---|---|
| H-01 | Mains energy via the host | Laptop on mains → ADuM4160 barrier fails → host earth reaches the floating island → current through the participant | Burn, ventricular fibrillation | 5 | 1 | 5 | ADuM4160 module, 5 kV RMS reinforced part (S-03, E-24); no carrier copper crosses the barrier; the isolation keep-out of DSN-EEG-003 Rev D §3.3 rule 4, enforced on all four copper layers; R1--R16 limit any resulting current | T20 per unit (500 V DC, ≥ 1 GΩ); supplier isolation certificate at T00; artwork creepage check on all four layer plots once per Gerber revision (TST-EEG-004 section 14). The Rev B DRC report lists no isolation keep-out violation on any of the four layers, and no violation of any other rule either; the check is still repeated on the Gerbers finally released, because no layout engineer has yet read this routing -- see 5.5 and SR-11 | 5 / 1 / 5 |
| H-02 | Barrier bypassed at the DevKit | Participant or operator plugs a mains-powered laptop into one of the DevKitC-1's own USB-C sockets instead of the isolator's | Same as H-01, with the barrier absent | 5 | 3 | 15 | Both DevKitC-1 receptacles physically blanked by the POD-P1 wall and the HM-01 shell (ASM-EEG-007 final check); one externally accessible data connector only, the isolator module's own USB-C through the POD-P1 aperture | Final-assembly safety check before labelling; first-article inspection; photograph in the unit record | 5 / 1 / 5 |
| H-03 | Excessive auxiliary current, single fault | One BAV99 half fails short → AVDD or AVSS on the module-side node → current out through the series resistor into the scalp | Sensation, in the limit a burn at a small contact | 3 | 2 | 6 | R1--R16 **68 kΩ** 0.1 % (ECO-EEG-024, applied 2026-09-02; 47 kΩ until that date); ±2.5 V rails rather than 5 V; zone split at x = 62 mm keeps V5V and DVDD3V3 away from every electrode net, on the signal layers and in the inner planes | Section 4 calculation; T23 per unit. **The calculated bare-resistor bound is 36.8 µA against a 50 µA limit, a 26 % margin, so S-02 is met in the design.** *Corrected 2026-09-02: this cell read "53.2 µA against a 50 µA limit, so S-02 is not met" while 47 kΩ was fitted.* The row is **still not closed**, for two reasons that the resistor change does not touch: nothing has been measured, and **SR-01 is the safety reviewer's finding and is open for their written disposition** | 3 / 2 / 6, **not closed** -- met in the design, open for sign-off and unmeasured |
| H-04 | Excessive auxiliary current, normal | Clamp and input leakage sum at the participant across 14 connections at 60 °C | Sensation | 2 | 1 | 2 | Same components; C0G filter capacitors; AC lead-off at 6 nA (E-06) | Section 4: 3.51 µA calculated against 10 µA; T23 per unit | 2 / 1 / 2 |
| H-05 | Light drive into an electrode | An LED conductor contacts an electrode conductor inside HM-01 | Sensation, tissue damage at 3.3 mA | 3 | 1 | 3 | ECO-EEG-014: two physically separate cables, WH-01 screened 12-way to J14 and WH-02 10-way to J30, separate glands, separate internal channels. **Added 2026-09-02**: the two conductors are also separated at the eight electrodes themselves, by 1.60 mm of printed PA12 between an outboard LED pocket and an inboard conductor pocket in `hm04()`, where the released body carried one undivided window through it -- see SF-9 | Harness insulation resistance ≥ 100 MΩ at 100 V DC between WH-01 and WH-02 at acceptance (WH-EEG-008); routing inspected at helmet build. **The site half of this control is drawn and not verified**: no HM-04 has been printed, the LED seat and its lead passages are still a WH-EEG-008 §3.1.1 proposal, and no insulation figure across the 1.60 mm web exists. The probability stays at P1 because the two-cable architecture already carried it; what changed is that the estimate is no longer contradicted by the electrode body, which is what ASM-EEG-007 open item 20 recorded | 3 / 1 / 3 |
| H-06 | Screen short in the electrode cable | One electrode conductor shorts to the drain wire inside WH-01 | Sensation | 3 | 2 | 6 | The **68 kΩ** series resistor is still in circuit; PTFE insulation tested ≥ 100 MΩ at 500 V DC; HARN_SHIELD joins DGND at R91 only | Section 4 SF-3: **36.8 µA calculated, inside the 50 µA limit**. *Corrected 2026-09-02: this cell read "WH-EEG-008 §5.5: 53 µA calculated, over the limit" against the 47 kΩ then fitted.* The same open point as SR-01 -- nothing is measured and the reviewer's disposition is owed | 3 / 2 / 6, **not closed** -- met in the design, open for sign-off and unmeasured |
| H-07 | Charging while worn | Participant plugs the charger in mid-session; both firmware interlocks fail | Participant island referenced to a consumer adaptor's secondary; up to ~250 µA AC | 3 | 2 | 6 | S-01 two mechanisms: session start refused while VBUS_DET is high, and CHG_CE held asserted for the session; separate charge-only receptacle at J24; label and participant card say it | T4 and T21 per unit | 3 / 2 / 6 |
| H-08 | Both interlocks are firmware | A firmware defect defeats S-01; there is no independent hardware inhibit | As H-07 | 3 | 2 | 6 | Two independent code paths, one sensing hardware (R84/R85), one driving hardware (CHG_CE) | T21 exercises both; **no hardware AND exists -- see SR-02** | 3 / 2 / 6, **decision owed** |
| H-09 | Cell thermal event in use | Internal short, crush after a drop, or charger fault → venting or fire on or near the head | Burn, inhalation injury | 5 | 1 | 5 | Protected 18650 with PCM; bq24074-class charger with thermal regulation; PTC F1 (1.1 A hold / 2.2 A trip) and TVS D24 on the charge input; polarised JST PH at J13 and the HM-10 keyed cell carrier | T00 cell lot documents (UN 38.3, IEC 62133-2) and cell OCV; M-04 drop with cell inspection | 5 / 1 / 5 |
| H-10 | Charging outside the safe temperature window | Kit charged in a cold or hot room; no thermistor path exists on the carrier | Lithium plating, later thermal event | 4 | 3 | 12 | bq24074 internal thermal regulation only; participant instruction to charge at room temperature | **J12 has no TS pin and J13 is a 2-pin connector, so S-04's thermistor is not fitted and E-23's 45 °C inhibit is untested and untestable. Neither requirement is met -- see SR-03** | 4 / 3 / 12, **not closed** |
| H-11 | Cell damaged in the return post | Participant drops the case; kit returns with a deformed or swollen cell | Fire in a courier vehicle or at goods-in | 5 | 2 | 10 | State of charge ≤ 30 % at despatch (S-09); cell inside equipment, retained, not loose; hard case; UN3481 PI967 section II marking and carrier documentation | Goods-in quarantine procedure (section 6.5); SVC-EEG-013 damage schedule | 5 / 1 / 5 |
| H-12 | Surface too hot against the skin | Two-hour session, pod at the occiput, warm room | Erythema, discomfort | 2 | 2 | 4 | About 0.6 W total; calculated rise 0.9 K in POD-P1 and 1.9 K in the smaller Phase 2 occipital shell; charging inhibited during a session | 3 h thermal type test with thermocouples on the TPU pads; limit 43 °C at any skin-contact surface | 2 / 1 / 2 |
| H-13 | Acoustic overexposure | Register default, corrupt stimulus file or calibration error drives the ES8388 headphone amplifier to full scale | Temporary threshold shift; in the limit permanent hearing damage | 4 | 3 | 12 | RFQ E-29: no more than 100 dB SPL at any commanded level, with the codec volume register clamped in firmware to the value measured at calibration; the clamp and level registers read back per unit at **TST-EEG-004 T17** and **T6**, not at run time -- the F-09 STATUS frame carries no level field; SW3 stop button; E-16 tap taken before any adjustable control | E-29 type test on an artificial ear, **TST-EEG-004 T28**, listed in TST section 14, once per lot; T17 headphone level per unit. **The ceiling is firmware only, there is no hardware limit, and calculated full-scale output is about 110 dB SPL -- see SR-04** | 4 / 2 / 8, **not closed** |
| H-14 | Chin strap entrapment | Strap catches on furniture or a chair arm as the participant stands | Neck compression, fall | 3 | 2 | 6 | HM-06 chin strap is removable and the runner says so before it is first mentioned; two anchor points at ear level so no loop can form around the neck; side-release buckle openable one-handed | Fit verification on a headform; the removability statement checked in the participant card | 2 / 2 / 4 |
| H-15 | Cable entanglement | 1.2 m headphone lead and the helmet harness while moving or reclining | Fall, device pulled from the head | 2 | 3 | 6 | Single lead, no loops; instruction not to wear while lying down, sleeping, cooking or driving; kit used seated at a desk | Participant card content review | 2 / 2 / 4 |
| H-16 | Drop damage in transit | Courier drops the case | Cracked frame, broken conductor, crushed cell | 2 | 4 | 8 | IP67 hard case; the **CASE-00 Rev C** die-cut PE insert of PKG-EEG-015 section 2.2 -- seven loose-laid 25 mm layers, 175 mm of stack, nine bays, every bay at least 3 mm larger than its part with 8 mm of foam between bays, the helmet hung at the halo on a shelf in the top layer with the electrode cups free of every surface; labelled bays and a packing photograph in the lid; outer carton (M-07). The two-sheet insert this row named at the first issue of this revision is withdrawn: PKG-EEG-015 section 2.4 shows 50 mm of foam cannot hold a 158 mm helmet | M-04 1 m drop type test on each face, run on the Rev C insert and not on the superseded two-sheet one, followed by a re-run of T3, T7, T8, T10, T14 to the same limits. The seven **Rev C cut files are drawn and shipped** -- `mech/CASE-00_foam_layer_1.dxf` to `_7.dxf`, the Rev B pair deleted -- and they are **not released for cutting** until the bought shell is measured (PKG-EEG-015 section 3.2), so **no insert has been cut**: the type test still has nothing to run against and this row's control is a schedule, not an insert | 2 / 3 / 6 |
| H-17 | Pressure injury | Eight assemblies at 3--6 N spring load for two hours | Local erythema, in the limit pressure necrosis | 2 | 3 | 6 | Contact force set by the spring, deliberately independent of the ratchet dial and the strap, so tightening cannot increase it; TPU 85A pads spread frame load | Fit verification; participant card instruction to stop if a site becomes painful. **The spring this control rests on is not yet a part.** AVL-EEG-017 K12 reads "3--6 N at working length, stainless 302", selected against the outside of the HM-04 body rather than against the seat the spring sits in, and it has never been specified against a geometry that could hold it: until 2026-09-02 the free height above the HM-05B spigot was 1.40 mm in an annulus 0.10 mm wide on the radius. HM-04's seat was deepened that day and the free height is now **3.50 mm**, so a 3--6 N spring is at least realisable, and it is still unspecified and unmeasured (PARTS-EEG-019 OA-20; ASM-EEG-023 Rev B, D5-K12-SPRING-ENVELOPE). Two things go to the safety reviewer with it: the force itself is the one thing the participant cannot adjust, so it is measured on five samples before any fleet order; and the spring's **solid height must stay below its working height through the whole 0.40 mm of travel**, because a stack that goes solid inside travel stops being a spring and transmits helmet force straight into the scalp for a two-hour session | 2 / 2 / 4 |
| H-18 | Abrasive prep gel injury | Untrained participant abrades their own scalp too hard, or gets gel in an eye | Skin break, eye irritation | 2 | 3 | 6 | Quantity limited to one 100 g tube; blunt-tip syringes; SDS in the kit; explicit instruction and a contraindication list; no IPA in the participant kit | IFU-EEG-014 content review; SDS on file per lot | 2 / 2 / 4 |
| H-19 | Skin sensitisation | Two hours' contact with dyed MJF PA12, TPU 85A, paste and ear cushions, repeated | Irritant or allergic contact dermatitis | 2 | 3 | 6 | ISO 10993-5 and -10 declarations required from every supplier (S-05); TPU pads and chin liner replaced every turnaround | **No declaration is on file for any material row in REG-EEG-012 §6.2, so S-05 is not met -- see SR-05**; REG-EEG-012 §6 defines a valid declaration | 2 / 3 / 6, **not closed** |
| H-20 | Cross-participant infection | Frame, ear clips, boom, cups and ear cushions circulate through about twenty people a year, and more over the fleet's life, with paste and abraded skin in the loop | Transmissible skin or scalp infection | 3 | 3 | 9 | Participant touches nothing removable; cups released with the HM-09 service key at refurbishment, ultrasonic cleaned and disinfected; TPU pads, chin liner and EMG pads discarded and replaced; frame wiped with 70 % IPA and never immersed | SVC-EEG-013 procedure with named agent and contact time; refurbishment record per kit. **The occurrence score is set against the annual population of about twenty and has not been re-scored against the fleet-life total; that is done at the safety review, section 7.3 item 4.14** | 3 / 2 / 6 |
| H-21 | Reprocessing degrades the parts | Bayonet seizes or the dye leaches after repeated IPA and ultrasonic cycles | A kit cannot be reprocessed; a declaration no longer holds | 2 | 4 | 8 | 25-cycle release-and-refit validation with disinfectant exposure on three assemblies, measuring release torque and retention at every cycle | DSN-EEG-002 finding 8 is recorded as **not resolved**; the validation belongs in the Phase 1 test plan -- see SR-07 | 2 / 3 / 6, **not closed** |
| H-22 | Data loss in the post | Case lost or opened in transit with the microSD card in it | Disclosure of raw EEG, the participant's voice and their home audio | 3 | 3 | 9 | Card holds pseudonymous kit and session identifiers only, never a name; card secure-erased at refurbishment after ingest; signed block chain detects tampering; the DPIA states the residual | REG-EEG-012 DPIA section; refurbishment record | 3 / 3 / 9 |
| H-23 | Unit mis-identification | A calibration record is attached to the wrong serial, or a module is swapped after provisioning | Wrong constants applied to a participant's data; a silent confound across the study | 3 | 3 | 9 | ATECC608B P-256 key is the device identity; iSerial, label and calibration record all derive from it in the `TIOV-B-nnnn` form defined in PKG-EEG-015 section 5; server verifies every signed block against the exported public key | T5, T6, T16 and the T18 label check; QP-EEG-010 forbids module swaps without full re-characterisation | 3 / 2 / 6 |
| H-24 | Contact light misreports | Clamp leakage or a lead-off calibration error puts a green light on a poor contact, or a red light on a good one | Unusable data; or, in this cohort, distress at a device that "will not work" | 2 | 4 | 8 | Lead-off is AC at 7.8 or 31.2 Hz and is detected at that frequency, so DC clamp leakage does not enter the reading; per-unit lead-off calibration against fitted references | T10 calibration against the three FIX-01/A 0.1 % thin-film references **4k99, 10k0 and 49k9**, recording the OPEN state and each reference on all eight channels and fitting a per-channel offset and slope by least squares (TST-EEG-004 section 14 T10; "5 k / 10 k / 50 k" was this row's rounding of those E96 parts, and it mattered once -- 49k9 through 47 kΩ and the 10 nF shunt read 92.5 kΩ, not the 92.6 kΩ that a true 50 k would give); T11 mapping. **Restated 2026-09-02 for ECO-EEG-024's 68 kΩ:** TST-EEG-004 T10 gives the three raw expectations as **70.5, 75.1 and 111.5 kΩ** at 7.8 Hz where they were 50.7, 55.5 and 92.5 kΩ at 47 kΩ, and the constants are re-derived from them; the 92.5 kΩ figure survives only as the arithmetic that settled the E96 naming. Calculated DC offset from 250 nA through **68 kΩ is 17.0 mV, 9.1 %** of the ±187.5 mV input range at gain 24, where it was 11.8 mV and 6.3 % at 47 kΩ (section 4.5) | 2 / 3 / 6 |
| H-25 | Device appears to act on its own | Contact lights come up at power-on, or during a recording block | Reinforcement of a persecutory belief, acute distress, at home, alone | 3 | 2 | 6 | LED_V is GPIO48, an input at reset: nothing can light at boot whatever the shift register holds. Lights forced dark during every recording block (E-27). R87 ties OE active and R88/C88 give the register a defined power-on state | T11 verifies both the mapping and the forced-dark state; the boot behaviour is a designed property of the pin, checked at first article. **The bicolour phase driver was written on 2026-09-02** (`firmware/main/main.c`), so the sentence this row carried until then -- that the driver was specified and not yet coded and that T11 could not pass -- is superseded on that date. Both `LOFF_STATP` and `LOFF_STATN` are now captured, which is what three colours need and one status byte cannot give: neither detector gone is green, exactly one gone is amber, both gone is red. Green is lit in phase A only, red in phase B only and amber in both. `LIGHT_PHASE_HZ` is 240, a 2.083 ms half-phase, but the alternation is a task delay and **quantises to the FreeRTOS tick**: 2 ms half-phases on a 1 kHz tick, so the rate on the built image is **about 250 Hz, not exactly 240**. That meets the "above 100 Hz" this control is written against, the two half-phases stay equal so the duty is 50/50 and the colour does not shift, and it is stated here rather than rounded away. `LED_V` is returned to an **input** whenever the lights are dark, which is the state the pin holds at reset and is the reason nothing can light at boot. **T11 can now be run and has not been run**: no unit exists, nothing has been measured, and the boot behaviour is still a designed property of the pin | 3 / 1 / 3 |
| H-26 | Radio suspicion | The ESP32-S3 contains a radio; the participant knows or discovers this | Belief that the instrument transmits; withdrawal; distress | 3 | 4 | 12 | Radio never initialised, no credentials stored (E-18, F-19); the fact is stated plainly to the participant together with how it is checked | T24 per unit sweeps 2.400--2.4835 GHz for 60 s during a recording block; result and firmware hash in the unit record | 3 / 2 / 6 |
| H-27 | Room microphone suspicion | An outward-facing microphone in the participant's home | Belief that the home is being monitored; withdrawal | 3 | 4 | 12 | Hardware mute on MIC_MUTE (GPIO21) reaching both J28.4 and J9.4; audio captured only in scripted windows; the mute state is shown in the runner and logged | T17 verifies the mute; T00 confirms the module's mute pin; the DPIA states what is captured and when | 3 / 3 / 9 |
| H-28 | The instrument is read as a verdict | A failed session, or a participant inferring a diagnosis from the recording | Distress, false confirmation or false refutation of their experience | 4 | 4 | 16 | No individual result is ever returned; the device performs no on-board analysis; the participant card and consent form state in plain words that the instrument cannot detect, confirm or refute anything about their experience; a staffed support pathway separate from the research team | Content review of IFU-EEG-014, the consent form and every public statement, against the prohibited-words list in REG-EEG-012 | 4 / 2 / 8 |
| H-29 | Distress with no one present | Any of H-25 to H-28 occurs at 23:00, alone | Acute psychological harm | 4 | 3 | 12 | SW3 red stop button with a distinct tactile feel ends the session without touching the laptop; the session can be abandoned at any point; support number on the lid card; withdrawal at any time with no reason given | Participant card content; SW3 verified at T17 | 4 / 2 / 8 |
| H-30 | Use error in placement | Ear clips swapped, EMG DIN leads mis-plugged, helmet on back to front | Bad data; a wasted session; participant self-blame | 2 | 4 | 8 | Electrodes permanently mounted, so there are no placements to get wrong; DIN sockets colour-coded and labelled; the runner holds the session until every site is green | T11, T18; placement guide in the kit. **To be re-read when the helmet's two new couplers are approved.** WH-EEG-008 §3.1.2 and §3.1.3, both specified on 2026-09-02 and neither signed, put a free-hanging touch-proof socket on each ear-reference tail and a third at the halo front for the Fpz bias lead, and add a fourth disposable pad to the three the participant already places. After that change the kit carries six sockets and six plugs of one 1.5 mm DIN 42802 family, so "electrodes permanently mounted, so there are no placements to get wrong" is true of the eight scalp sites and no longer of the whole instrument, and the cross-mate of WH-EEG-008 open item 24 is a use error this row has not scored. The scoring waits on the safety reviewer and the programme lead, who between them decide whether the ear clips travel mated and captive; it is not re-scored here on an unsigned proposal | 2 / 3 / 6 |
| H-31 | Battery hatch opened | Participant opens the HM-08 hatch to "check" the device | Cell damage, short, exposure to the pack | 3 | 2 | 6 | Quarter-turn hatch, no tool supplied; HM-09 service key deliberately absent from the participant kit; instruction not to open | Kit packing list check at T18 that no service key is present | 3 / 1 / 3 |
| H-32 | Wrong headphones fitted | Participant substitutes their own | Calibrated level invalid; possible overexposure at a different sensitivity | 3 | 3 | 9 | Same headphone model in every kit (A-04, 32 to 64 Ω; the shipped ATH-M20x is 47 Ω) so the calibrated level is transferable; the E-29 clamp is set on the shipped model; instruction not to substitute; level logged in session metadata | Content review; the commanded level is logged in the session metadata, so a mismatch is detectable after the fact. **There is no run-time readback: the F-09 STATUS frame carries no level field, so nothing tells the runner during a session** | 3 / 3 / 9 |

Rows H-03, H-06, H-08, H-10, H-13, H-19 and H-21 are **not closed**. H-03 and H-06 carry
SR-01, H-08 carries SR-02, H-10 carries SR-03, H-13 carries SR-04, H-19 carries SR-05 and
H-21 carries SR-07. They are the reason section 7 exists.

---

## 4. Patient auxiliary current budget

This section is the calculation RFQ-EEG-001 Rev E S-02 points to, and it is the single home of
the series-resistor noise-and-flatness arithmetic that the rest of the package cites rather than
recomputes. **The resistor is 68 kΩ from 2026-09-02** (ECO-EEG-024); where a 47 kΩ figure appears
below it is labelled as the superseded one and kept only so the correction is legible. It is arithmetic on datasheet figures, not a measurement. Nothing in this package
has been measured.

### 4.1 Limits and applied parts

S-02: **≤ 10 µA DC** and **≤ 100 µA AC** in normal condition, including the lead-off
excitation; **≤ 50 µA DC** in single fault. S-02 states no AC single-fault limit; IEC 60601-1
allows 500 µA AC in single fault for a type BF applied part and this pack uses that figure,
flagged as an addition the reviewer must ratify.

There are **fourteen** patient connections: eight scalp electrodes (E_Fz, E_Cz, E_Pz, E_C3,
E_C4, E_T7, E_T8, E_F7), two ear references (REF_L, REF_R) and the bias lead (BIAS_EL) at
J14.1--J14.11, plus three EMG leads at the DIN 42802 sockets J15, J16, J17. That is
8 + 2 + 1 + 3 = 14, and fourteen is the number every document in the package uses; where
another document says thirteen it is wrong and is corrected. The two spare EOG channels
(EOGIN1/2 at J22) are protected identically but are not fitted to a panel socket in a standard
build; they are excluded from the sum and included in the fault analysis.

Every one of the fourteen passes through the same network: a **68 kΩ** 0.1 % 25 ppm thin-film
resistor (R1--R16, Vishay TNPW060368K0BEEA -- **corrected 2026-09-02**, ECO-EEG-024; it was 47 kΩ
TNPW060347K0BEEA until that date), a BAV99 dual clamp to AVDD/AVSS (D1--D16,
Nexperia BAV99,215 -- BAT54S is not approved in this position) and a 10 nF C0G capacitor to
AGND_REF (C1--C16, Murata GCM1885C1H103JA16D). The analogue rails are **AVDD = +2.5 V and
AVSS = −2.5 V** referred to AGND_REF, which is the analogue mid-rail and not ground.

**As of 2 September 2026 that is true of the topology as well as of the values.** Until that
date channel 11 was wired as an exception: `D11.3` and `C11.1` sat on `BIAS_EL`, the patient side
of R11, so the clamp and the filter of the bias channel were in front of its protection resistor
rather than behind it. The override in `tools/design.py` that did it is deleted and the row is
generated by the generic loop, so channel 11 now reads R11.1 = BIAS_EL (patient),
R11.2 = BIASOUT (module), D11.3 = BIASOUT, C11.1 = BIASOUT and C11.2 = AGND_REF, which is the
wiring of the other fifteen. R11 is 68 kΩ with the rest of them. **C11 stays fitted**, at the same 10 nF C0G Murata
GCM1885C1H103JA16D: RFQ-EEG-001 Rev E E-07 requires sixteen networks with C1--C16 all 10 nF C0G,
and depopulating one of them would breach a mandatory line of the top-level specification
silently. What the change does to the fault analysis is SF-1a and SF-6a of section 4.4; the
finding it closes in the design is **SR-12**, whose disposition is still the reviewer's to sign.

J15 to J17 are named in design.py as a Stäubli SLB1,5-F class part rather than a confirmed
PCB-mount catalogue item, and no touch-proof 1.5 mm socket with a PCB signal pin and two
retention posts has yet been first-articled. That is an open sourcing item on a Class A
patient-safety part and is carried in AVL-EEG-017; it does not change the arithmetic below,
because the socket is a connector and not an impedance.

### 4.2 Normal condition, DC

| Term | Source of the figure | Per connection at 25 °C | Per connection at 60 °C |
|---|---|---|---|
| BAV99 reverse leakage, one half | Nexperia BAV99,215 datasheet: I_R ≤ **100 nA** at V_R = 75 V, T_amb = 25 °C; I_R ≤ **2.5 µA** at V_R = 75 V, T_j = 150 °C | 100 nA | **246 nA**, interpolated |
| ADS1299 input bias | Datasheet 300 pA typical; no maximum is specified, so the budget uses a 1 nA engineering bound | 1 nA | 1 nA |
| C0G filter capacitor insulation leakage | IR ≥ 10 GΩ at 2.5 V | 0.25 nA | 0.25 nA |
| OPA4376 inputs | 0.2 pA typical, and not patient-connected: U1--U3 sit in the envelope path only | 0 | 0 |
| **Per connection** | | **0.101 µA** | **0.251 µA** |

The 60 °C figure is interpolated between the two datasheet points on the assumption that
leakage doubles every 26.9 K, which is what those two points imply: 25 × over 125 K. No credit
is taken for the fact that the clamp sees ±2.5 V rather than the 75 V of the datasheet
condition, which would reduce the figure by roughly the square root of the voltage ratio. The
budget is therefore conservative by a factor of about five on its dominant term. It also
assumes one diode of each BAV99 leaks at maximum while its partner leaks nothing, so no
cancellation is claimed.

Aggregated as the standard measures it -- the measuring device between one patient connection
and the other thirteen tied together, every one of the thirteen sourcing in the same direction:

    25 °C:  0.101 + 13 x 0.101 = 1.41 uA
    60 °C:  0.251 + 13 x 0.251 = 3.51 uA        against 10 uA

**Margin: 2.85x at 60 °C.** The 60 °C internal temperature is an assumption for a pod
dissipating 0.6 W; it must be confirmed by the 3 h thermal type test, and the reviewer should
treat the DC budget as provisional until it is.

### 4.3 Normal condition, AC

| Term | Working | Value |
|---|---|---|
| Lead-off excitation (E-06) | 6 nA AC at 7.8 or 31.2 Hz, enabled on channels 1--8 of device 1 only (LOFF_SENSP 0xFF); worst case all eight sum through one connection | 0.048 µA |
| Displacement current across the isolation barrier | ADuM4160 C_I/O ≈ 2.2 pF (datasheet) plus an estimated 15 pF of module PCB and connector stray, budgeted at 20 pF. Worst case a mains-referenced host at 230 V RMS, 50 Hz: I = 2π·50·20e−12·230 | 1.45 µA |
| **Total** | | **1.50 µA** against 100 µA |

**Margin: 67x.** The 15 pF stray is an estimate, not a measurement: the module is a generic
breakout with an uncontrolled layout. Even at ten times that figure the total is 15 µA and the
budget still closes.

### 4.4 Single-fault conditions

Two bounds are given for each fault. **Bound A** is the bare-resistor bound: the fault voltage
divided by one series resistor, with a zero-impedance return, and no measuring device. It is not
what IEC 60601-1 measures, and it is the number this pack judges against, because the reviewer
should be shown the worse case. **Bound B** is the current the standard's own measurement would
read: through the series resistor, through the figure-12a measuring device (10 kΩ at DC), and back
through the other thirteen resistors in parallel.

**Restated 2026-09-02 for ECO-EEG-024.** At the 68 kΩ now fitted, bound B's loop is
68 + 10 + 68/13 = **83.231 kΩ**. Until that date the resistor was 47 kΩ and the loop was
47 + 10 + 3.615 = 60.615 kΩ; both of those figures are superseded as statements of the design and
are quoted below only in the "was" column.

| # | Fault | Working | Bound A | Bound B | Verdict |
|---|---|---|---|---|---|
| SF-1 | One BAV99 half fails short, AVDD on the module-side node | 2.5 V / 68 kΩ; 2.5 V / 83.231 kΩ | **36.8 µA** | 30.0 µA | **Passes both bounds**: 26 % margin on bound A, 1.67× on bound B. **Restated 2026-09-02 (ECO-EEG-024).** Until that date the working was 2.5 V / 47 kΩ and 2.5 V / 60.615 kΩ, the bounds were **53.2 µA and 41.2 µA**, and this row read "fails bound A by 6.4 %". Those two figures are superseded. Nothing has been measured, and SR-01 is open for the reviewer |
| SF-2 | One BAV99 half fails short, AVSS on the node | mirror of SF-1 | −36.8 µA | −30.0 µA | as SF-1. *Was −53.2 µA / −41.2 µA at 47 kΩ; superseded 2026-09-02* |
| SF-3 | One electrode conductor shorts to the WH-01 drain wire | same source, same 68 kΩ (WH-EEG-008 §5.5) | **36.8 µA** | 30.0 µA | as SF-1. *Was 53 µA / 41 µA at 47 kΩ, which WH-EEG-008 §5.5 called "over the limit"; superseded 2026-09-02, and this fault now sits inside the 50 µA limit like every other* |
| SF-4 | R_n fails short, clamp intact | clamp leakage alone, unlimited by R | 0.251 µA | 0.251 µA | Pass, 200× margin. Breaks the RF filter and the noise budget; a functional failure, not a safety one |
| SF-5 | R_n fails open | no path | 0 | 0 | Pass. Channel reads open at lead-off; the contact light stays red |
| SF-6 | C_n fails short to AGND_REF | no source | 0 | 0 | Pass. Dead channel, caught at T8 and T10 |
| SF-6a | **C11 fails short to AGND_REF -- closed by the design change of 2026-09-02** | C11 now sits on BIASOUT with the other fifteen filters, so this short ties the module's bias output to the analogue mid-rail and reaches the participant's Fpz electrode only through the full 68 kΩ of R11 (47 kΩ until ECO-EEG-024 was applied on 2026-09-02) | 0 (no source) | 0 | **Pass, exactly as SF-6.** Nothing is injected, the bias drive is dead, and the channel is caught at T8 and T10: a functional failure, not a safety one. **Superseded on 2026-09-02.** Until that date this row read that C11 sat on BIAS_EL, the patient side of R11, so that the short was "a galvanic bond from the Fpz bias electrode to the analogue mid-rail with NO series resistance", that it was "not a dead channel", and that after it the IFU-EEG-014 §14 sentence "There is no earth connection anywhere in this instrument" was false. It was referred to the safety reviewer as SR-12. The move closes it on its own: with C11 on BIASOUT no fault of this capacitor bonds an electrode to the mid-rail except through the full series resistor, and the IFU sentence survives the fault |
| SF-1a | **One D11 BAV99 half fails short -- closed by the design change of 2026-09-02** | D11 now sits on BIASOUT, so a shorted half puts AVDD or AVSS on the module-side node of channel 11 and reaches the Fpz electrode through R11, exactly as on the other fifteen channels. **ECO-EEG-024 was applied the same day**, so bound A is 2.5 V / 68 kΩ and bound B is 2.5 V / 83.231 kΩ; at the 47 kΩ this row was first written against they were 53.2 µA and 41.2 µA | **36.8 µA** | **30.0 µA** | **This fault is now the ordinary SF-1 and is judged with it**: it passes both bounds like every other channel, so it carries no figure and no finding of its own and is covered by SR-01. **Superseded on 2026-09-02.** Until that date D11 sat on BIAS_EL, the patient side of R11, so this row read "AVDD or AVSS reaches the Fpz electrode with NO series resistor in the path", bound A was **unbounded** for want of a series element, bound B was 2.5 V / 13.615 kΩ = **183.6 µA**, and the row failed S-02 on both bounds, bound B by 3.7×, on the one driven conductor that terminates on a forehead. **That 183.6 µA figure is withdrawn**, here and wherever else in the package it is quoted as the consequence of energising BIAS_EL -- including as the stated consequence of a mis-mate into a bias socket. The bound on BIAS_EL is now the ordinary SF-1's |
| SF-7 | AVDD rail rises to 5 V through a module regulator fault | the clamp is reverse-biased at rest and does not conduct; the electrode node stays at AGND_REF | 0 | 0 | Pass. A rail fault alone injects nothing |
| SF-8 | V5V or DVDD3V3 bridged onto an electrode node | 5.0 V / 68 kΩ = 73.5 µA if it could happen -- 106 µA at the 47 kΩ fitted until 2026-09-02; either way over the limit, which is why the row rests on the exclusion and not on the resistor | -- | -- | **Excluded as not credible.** The zone split at x = 62 mm, the ELECTRODE netclass (0.30 mm track, 0.40 mm clearance) and the 0.35 mm minimum electrode clearance mean no electrode net is ever adjacent to a rail above ±2.5 V on any of the four layers. The two inner planes left of x = 62 mm are AGND_REF, not a supply, so the copper directly above and below every electrode trace is the analogue mid-rail. This is why the bipolar rail choice is a safety control and not only a signal-chain one. Verified in `kicad/EEG-CAR-01_RevB_DRC_report.txt`, which records zero digital nets in the analogue zone and no clearance violation anywhere on the board, the 0.35 mm electrode rule included. That is an automatic check on an unreviewed routing (SR-11), and it is re-verified on the routed Gerbers of whichever revision is finally released |
| SF-9 | An LED conductor contacts an electrode conductor | 3.3 V through R70--R77 (1 kΩ) = 3.3 mA | -- | -- | **Excluded as not credible after ECO-EEG-014**: two separate cables, two connectors, two glands. No series resistance in the light drive can control this fault -- raising R70--R77 to 47 kΩ would give 70 µA and still fail, and 100 kΩ would extinguish the lights. (Those are hypothetical values for the LED resistors and are not R1--R16, which ECO-EEG-024 took to 68 kΩ; R1--R16 are not in this fault path at all, because the contact is inside the helmet on the patient side of them.) The control is physical separation and its verification, nothing else. **Strengthened at the site on 2026-09-02, and not eliminated.** The exclusion rested on ECO-EEG-014's two cables, two connectors and two glands, and ASM-EEG-007 open item 20 recorded that the frame as built did not support it at the electrode: `hm04()` cut the contact-light window as ONE box straight through a 12.40 mm body, so its inboard and outboard openings were the two ends of a single undivided cavity, and any scheme putting the electrode conductor in one end and the switched LED in the other had them sharing open, gel-flushed volume at all eight sites. `tools/mech_gen.py hm04()` now cuts **two pockets, 3.20 mm wide, with 1.60 mm of printed PA12 between them** -- outboard the LED seat, inboard the conductor run -- and the released mesh is regenerated (HM-04 model volume 1.86 cm³, `mech/MANIFEST.json`). The separation is now made of material rather than of distance, which is the only form of it this fault respects. What is still owed before the row may be called verified: **nothing has been printed**; the LED seat, its two lead passages, the dressed conductor exit and the HM-04A anchorage are still proposals in WH-EEG-008 §3.1.1 and not released geometry; both pockets open onto the outside faces of the body and the gel path runs through the same region; and no insulation or creepage figure across the 1.60 mm web has been calculated or measured. The control is unchanged in kind -- physical separation and its verification -- and only the separation half has moved |
| SF-10 | Isolation barrier fails short, host on mains | The host's own touch current flows through the participant. A Class II supply is limited to 250 µA to earth, implying ≈ 3.46 nF of Y-capacitance and a 919 kΩ source; the 68 kΩ series resistor adds 7.4 % to that source, giving 230 V / 987 kΩ. *Restated 2026-09-02: at the 47 kΩ previously fitted this read "47 kΩ adds 5 %" and ≈ 237 µA* | ≈ **233 µA** AC | -- | Within the IEC 60601-1 500 µA AC single-fault allowance for a type BF applied part. **S-02 states no AC single-fault limit and must be amended -- SR-06** |
| SF-11 | Both charge interlocks fail, participant charges while wearing | As SF-10, with the consumer adaptor's secondary in place of the host | ≤ 250 µA AC | -- | As SF-10. The interlocks reduce probability, not severity |
| SF-12 | Headphone amplifier fault puts DC on the 3.5 mm sleeve | HP_GND is a carrier net referenced to DGND, inside the floating island; the ear cushions are insulating | 0 | 0 | Pass. No mains reference exists on that conductor |
| SF-13 | An electrode net shorts to an inner reference plane through a lamination or via defect | The plane under every electrode trace is AGND_REF, the analogue mid-rail, so the fault source and the electrode reference are the same node | 0 | 0 | Pass on safety, and this is a consequence of the four-layer change worth stating: the new copper the change added under the electrodes is at 0 V analogue, not at a supply. It is a functional failure -- a dead or shorted pair of channels, caught at T8 and T10 |

**What the channel 11 change closes, and what it leaves.** It closes SF-1a and SF-6a, and it
closes them by moving two components rather than by argument: the fault paths those two rows
described do not exist on the board that `tools/design.py` now generates. It closes SR-12 **in the
design only**. The finding belongs to the safety reviewer of section 7, section 11 records its
disposition as theirs to write, and this pack may not record it as closed on the strength of the
programme having taken the option the analysis recommended. Two things travel with the change and
neither is a patient-current fault.

*The one thing the package cannot compute.* With C11 on BIASOUT the series resistor no longer
isolates the module's bias amplifier from 10 nF of C0G at its own pin, and no document here establishes that
the amplifier is stable driving it. The module is not bought, and the bias loop closes inside it:
ICD-EEG-006 §1.1 records at J2 that BIASOUT is an output of the module and that BIASIN is driven
by nothing on the carrier. No ADS1299 datasheet figure answers for a third-party module's output. It is therefore declared where this package declares everything it assumes about that
module: as a row in **ICD-EEG-006 §2.1's assumption table**, "Bias amplifier stable driving 10 nF
C0G at BIASOUT, with 68 kΩ in series to the electrode", with the
consequence if untrue that the bias loop peaks or oscillates and common-mode rejection degrades on
all sixteen channels. That is an incoming-qualification condition on a supplier not yet chosen and
a first-article scope check, and it is the **module-qualification owner's** to accept before any
PIEEG-8-class module is qualified, and to carry into the RFQ pack. The same §1.1 note is itself
owed a correction: it still records D11 and C11 as sitting on `BIAS_EL`, "the patient side of it,
where the other fifteen have their clamp and filter on the module side", and cites SF-1a, SF-6a
and SR-12 for the consequence. That sentence is superseded on 2026-09-02 and its repair belongs to
ICD-EEG-006's owner, not to this pack. The safety exposure if the assumption is wrong is bounded and
functional, not a fault current: an oscillating bias amplifier is rail-limited and reaches the
forehead only through the 68 kΩ, so at most about 37 µA AC -- it was about 53 µA at 47 kΩ -- inside the 100 µA AC normal-condition
allowance of section 4.3 for a type BF applied part, and it presents as degraded CMRR on a bench
rather than as a hazard on a head. If first article shows peaking, the cheap directions are all
still open with the pad populated: depopulate C11, or drop to the 4.7 nF C0G same-series alternate
that AVL-EEG-017 already approves on a written ECO, or fit ≤ 1 nF behind a 10 kΩ isolation
resistor as a schematic change. The expensive direction is the other one, which is why C11 is
fitted now.

*The 183.6 µA is withdrawn, and nothing else closes with it.* Any document that cites 183.6 µA as
the consequence of putting an electrode or a fault on BIAS_EL is superseded from 2026-09-02,
including the mis-mate case raised against a free-hanging bias socket -- a K2 ear clip or a K3 EMG
lead entering it now lands on a node bounded by the ordinary SF-1, not on an unresisted one. The
mis-mate itself is a use-error item and stays open where it is raised, in WH-EEG-008's open item
24 and in the register of connector cross-mates; it is not closed here and it is not closed by
this change. Nor did touch-proofing that interface ever close SR-12: a connector does not alter
what flows out through an electrode. The topology change is what closes SR-12 in the design, and
the reviewer's signature is what closes it in this pack.

### 4.5 Conclusion and the margin

| Limit | Calculated | Margin | Closes? |
|---|---|---|---|
| Normal, DC ≤ 10 µA | 3.51 µA at 60 °C | 2.85× | Yes |
| Normal, AC ≤ 100 µA | 1.50 µA | 67× | Yes |
| Single fault, DC ≤ 50 µA | **36.8 µA** (bound A) / 30.0 µA (bound B) | 1.36× / 1.67× | **Yes, on both bounds, in the design.** *Restated 2026-09-02: at the 47 kΩ fitted until that date this row read 53.2 µA / 41.2 µA, −6.4 % / 1.21×, and "No, on bound A".* It is met by calculation, it is not measured, and SR-01 is open for the reviewer |
| Single fault, AC (not stated in S-02) | ≈ 233 µA | -- | Limit missing |

**SR-01 -- the finding that matters. Restated 2026-09-02, and still open.**

*What it said until that date.* With ±2.5 V rails and 47 kΩ, the single-fault DC budget did not
close on the bare-resistor bound: 2.5 V / 47 kΩ = 53.2 µA against the 50 µA limit of S-02, a 6.4 %
overshoot. It closed on the measurement the standard actually prescribes, but only by 17 %. That
overshoot stood through three revisions.

*What is true now.* **ECO-EEG-024 is applied.** R1--R16 are 68 kΩ, so 2.5 V / 68 kΩ = **36.8 µA**
on bound A and 2.5 V / 83.231 kΩ = **30.0 µA** on bound B, against 50 µA. **S-02 is met in the
design, on both bounds**, and this pack says so plainly because it is what the arithmetic gives.
The disposition the pack recommended below -- option 2 -- is the one the programme took.

*Why the finding is still open.* Three things did not change when the resistors did. **Nothing has
been measured**: the figure is arithmetic on datasheet values, the interpolated BAV99 leakage among
them, with no measurement anywhere in the package and no accredited laboratory available to the
programme. **No unit exists** to measure. And **the finding belongs to the safety reviewer**, not
to the programme: a design change made by the people who wrote the analysis is not a disposition,
and section 7 exists precisely so that someone outside the programme signs one. SR-01 therefore
stays **Open** in section 10, and section 7.3 item 4.3 is the form it closes on. What the reviewer
is asked has changed, and that is the whole of the change: they are handed a design that **meets**
the limit and asked to confirm it, rather than one that does not and asked to accept it. The three
dispositions are kept below because the reviewer may still direct any of them:

1. **Accept bound B.** Record that the compliant measurement reads 41.2 µA calculated, accept
   the 17 % margin, and require T23 on every unit as the routine evidence. No change to the
   board. Cheapest and weakest.
2. **Raise the series resistance to 68 kΩ. THIS IS THE DISPOSITION THE PROGRAMME TOOK, on
   2026-09-02, as ECO-EEG-024; it is applied in `tools/design.py` and awaits the reviewer's
   ratification, not their selection.** R1--R16 are **68 kΩ 0.1 % thin film** in the
   same 0603 footprint with the already-approved **10 nF C0G** capacitor, so sixteen parts
   changed and nothing moved. 2.5 V / 68 kΩ = **36.8 µA**, a 26 % margin under the 50 µA limit.
   The consequences, all calculated:

   | Property | 47 kΩ / 10 nF (superseded 2026-09-02) | 68 kΩ / 10 nF (ECO-EEG-024, **fitted**) | Requirement |
   |---|---|---|---|
   | Single-fault bound A | 53.2 µA | **36.8 µA** | S-02 ≤ 50 µA |
   | Single-fault bound B | 41.2 µA | **30.0 µA** | S-02 ≤ 50 µA |
   | Corner frequency | 339 Hz | **234 Hz** | -- |
   | Loss at 100 Hz | −0.36 dB | **−0.75 dB** | **E-10 states both branches: ±0.5 dB at 47 kΩ and ±1.0 dB at 68 kΩ. ECO-EEG-024 is taken, so the ±1.0 dB branch is the one in force.** Both states are stated together wherever E-10 appears |
   | Johnson noise, 0.5--70 Hz | 0.233 µV | **0.28 µV** | -- |
   | Total input-referred noise with the ADS1299's 0.14 µV | 0.27 µV | **0.31 µV** | E-03 ≤ 1.0 µV |
   | DC offset from 250 nA clamp leakage | 11.8 mV, 6.3 % of range | **17.0 mV, 9.1 % of the ±187.5 mV range at gain 24** | headroom only |

   The noise cost is 0.04 µV and the budget still has more than 3× of margin. The real cost is
   passband flatness: 68 kΩ into the same 10 nF pulls the corner down to 234 Hz and costs
   0.75 dB at 100 Hz. **E-10 already states both branches and permits ±1.0 dB for exactly this
   case**, so taking the disposition moved the requirement onto that branch rather than breaching
   it; ECO-EEG-024 carries the widening with the resistor change, and TST-EEG-004 T22 grades
   against ±1.0 dB on the 68 kΩ build. The wider band is earned by the 68 kΩ and by nothing else.
   Rev A of this pack proposed 100 kΩ with the
   4.7 nF alternate instead; that reaches 25 µA but changes thirty-two parts, changes the
   approved capacitor value and raises the noise to 0.37 µV, and 68 kΩ buys enough margin for
   less disturbance. **The ruling is 68 kΩ, recorded as ECO-EEG-024.**
3. **Requalify the clamp.** Return to a low-leakage TVS (Nexperia PESD5V0X1BL class, the part
   the Rev A internal BOM carried) and keep 47 kΩ. This does not help: the fault is a *short*,
   not leakage, and 2.5 V across 47 kΩ is 53.2 µA whatever the clamp is. Recorded here so the
   reviewer does not have to rediscover it.

**What is actually built. Restated 2026-09-02.** *Until that date this paragraph read that the two
Phase 1 prototypes were "fabricated and assembled with 47 kΩ fitted" while ECO-EEG-024 stayed open.
Both halves of that are now wrong: **no prototype has been fabricated or assembled** -- nothing in
this package has been built -- and **ECO-EEG-024 is applied, not open**.* What is true is that
`tools/design.py` fits 68 kΩ, that the carrier BOM and the fabrication data carry 68 kΩ, that
ECO-EEG-024 is recorded in the register ECO-EEG-016 against EEG-CAR-01 Rev B, RFQ-EEG-001 E-07 and
E-10, the carrier sub-BOM and TST-EEG-004 T22's calculated expectation, and that E-10 therefore
stands on its ±1.0 dB branch. The two Phase 1 prototypes, when they are built, are built with
68 kΩ. **The measurement of the real single-fault current on a Phase 1 unit is still made before
the Phase 2 build is released, and the reviewer's disposition is taken then.** The design meets
S-02; the *finding* SR-01 stays open until the reviewer signs and the measurement exists.

### 4.6 How the limit is verified and who signs it

Routine per-unit evidence is TST-EEG-004 **T23**, fourteen DC and fourteen AC readings, host
connected and disconnected, plus fourteen single-fault DC readings -- seventy values in the
unit record. T23 states its own limitation plainly: it uses a 100 kΩ measuring resistor rather
than the figure-12a network and applies one single-fault condition. It is a stand-in.

The real verification of S-02 is a type test with an MD-2 measuring device per IEC 60601-1
figure 12a applied at each of the fourteen terminations, normal and single fault, on one Phase
1 unit, witnessed by the safety reviewer. It does not exist yet and the pack does not pretend
otherwise. **Sign-off: the safety reviewer, on the section 7 form, item 4.3.**

---

## 5. Creepage, clearance, and why the carrier has none to check

### 5.1 Where the barrier is

The barrier is entirely inside the ADuM4160 module at J10. The host receptacle is on the
module -- USB-B on the only named candidate, brought to a panel USB-C by the WH-09 pigtail,
which is a live non-conformance against E-24 and is stated as such in section 5.4. The four
carrier pins are `VDD_ISO`, `USB_DN`, `USB_DP`, `DGND` -- every one of them on the device
side. There is no host-side net anywhere in design.py's netlist, on any of the four
layers, at any coordinate. **The carrier has no isolation barrier, and therefore has no
creepage or clearance across one to assess.** That is the whole isolation strategy in one
sentence, and it is the reason the carrier needs no milled creepage slot: not because of how
many layers it has, but because no conductor on it is ever mains-referenced.

The layer count changed during layout and the reviewer should know what it does and does not
change here. EEG-CAR-01 Rev B is a **four-layer** board -- L1 signal, L2 reference plane, L3
reference plane, L4 signal, with AGND_REF left of x = 62 mm and DGND right of it on both inner
layers, stitched together only at the R90 star point. Package v1 argued that two layers would
be enough; doing the layout showed that on two layers the bottom side would have to be both
the reference plane and the second routing surface, and it cannot be both. For the isolation
case the four-layer change is neutral in principle and adds work in practice: there are now
**four** copper layers on which the keep-out under the barrier must be proved, and two of them
cannot be inspected on a finished board. Two properties make that verifiable rather than
hopeful. Vias are **through vias only** -- no blind, buried or back-drilled structures -- so
every hole in the barrier region appears in the drill file and on both outer plots. And the
keep-out is encoded as a rule area on all four copper layers, so the DRC proves it rather than
a person measuring a plot. In the Rev B routing it does: `kicad/EEG-CAR-01_RevB_DRC_report.txt`
lists no isolation keep-out violation on any of the four layers. Section 5.5 gives that result
with its figures, and states what the same report does and does not settle.

The consequence, which the reviewer should hold on to: the entire safety case for S-03 rests on
a purchased breakout board whose layout the programme does not control.

### 5.2 What the barrier must achieve

Working voltage on the host side is mains, taken as 250 V RMS, pollution degree 2, material
group IIIb unless the module vendor declares better.

| Means of protection | Creepage | Air clearance | Dielectric strength | Source |
|---|---|---|---|---|
| 1 MOOP | 2.5 mm | 2.0 mm | 1500 V AC | IEC 60601-1 table 13/16 |
| 1 MOPP | 4.0 mm | 2.5 mm | 1500 V AC | IEC 60601-1 table 12/11 |
| 2 MOPP | 8.0 mm | 5.0 mm | 4000 V AC | IEC 60601-1 table 12/11 |
| **ADuM4160 in RW-16** | **≥ 8.0 mm** external | **≥ 8.0 mm** external | **5000 V RMS, 1 min** | Analog Devices datasheet; reinforced per DIN V VDE V 0884-10, CTI ≥ 600 V (material group I) |

The part itself therefore exceeds S-03's ≥ 2.5 kV RMS requirement and meets 2 MOPP distances
at 250 V. What the part achieves and what the *module* achieves are different questions, and
only the second one matters. The module's own barrier pad-to-pad spacing, its silkscreen and
mask over the barrier, and any Y-capacitor fitted across it are all outside the programme's
control.

### 5.3 The keep-out under the barrier

The one thing the carrier can do about a barrier it does not carry is refuse to put copper
underneath the half of the module that is mains-referenced. It does. The keep-out's
coordinates and layer scope are stated once, in **DSN-EEG-003 Rev D section 3.3 rule 4**, and
are not restated here. What this pack adds is the safety consequence and the geometry that
carries it:

| Property | Value |
|---|---|
| Region | The rule area of DSN-EEG-003 §3.3 rule 4, a 9.0 × 20.0 mm rectangle reaching the x = 150.0 mm board edge |
| Layers | No copper on **any of the four layers**: no pour on L1 or L4, **no plane copper on L2 or L3**, no via, no track, no test point, no silkscreen conductor. The inner planes are the part a visual check cannot see and the part the DRC rule area exists for |
| J10 position | (136.0, 6.0), a 1×4 socket running in +Y; pins span y = 6.00 to 13.62 mm at x = 136.0, clear of the keep-out edge |
| Nearest other part | J11 (ATECC608B) at (136.0, 20.0) -- device side, outside the barrier region |
| Encoding | A KiCad rule area on all four copper layers plus a custom DRC rule, so that this one dimension is proved by the check and not by an eye. It is proved in the Rev B report, which lists no isolation keep-out violation and no violation of any other rule either. Section 5.5 says what that settles and what it does not |

MP-01, the printed module plate, positions the ADuM4160 module above the carrier so that the
device half sits over J10 and **the whole of the host half -- the module's own host receptacle
(USB-B on the named candidate, panel USB-C via WH-09, section 5.4), the host-side VBUS and
ground copper, and the host-side half of the ADuM4160 body -- lies in plan view inside the
keep-out rectangle.** No carrier conductor, on any layer, is beneath any of it.

### 5.4 The slant path, and what is still not fixed

The plan-view keep-out removes carrier copper from under the host half, but the shortest path
from a carrier conductor at the keep-out edge to a host-side module conductor does not run in
plan view. It runs over the edge of the keep-out and up through the standoff to MP-01. That
combined slant distance must be at least the 8.0 mm of 2 MOPP at 250 V.

**This is now closed.** The carrier-to-plate standoff is fixed at **M3 × 18 mm nylon hex,
female-female, four off at MH1--MH4, with eight M3 × 6 nylon pan screws**, and MP-01 is
**146.0 × 126.0 × 3.0 mm**. The vertical component of the slant path is therefore 18.0 mm
before any horizontal component is added, which is more than twice the 8.0 mm the safety case
asks for, with no reliance on the horizontal offset at all. The standoff height also fits the
enclosure: floor 2.5 + boss 6.0 + carrier 1.6 + standoff 18.0 + plate 3.0 + modules ≤ 18.0 =
**49.1 mm** against the 55.5 mm internal depth of POD-P1, a margin of 6.4 mm. **SR-08 is
closed on that ruling**, and the consequence is that the standoff height is now a
risk-control dimension: section 9 lists it, and shortening it reopens the finding.

> **Open: the module is uncontrolled.** No vendor has been fixed for the ADuM4160 breakout and
> no vendor board file or dimensioned drawing has been obtained. Until one is, the module's own
> creepage is unknown, and so is the exact position of its host-side copper relative to the
> keep-out. This is the weakest link in the entire safety case and is named as such. It is
> SR-09, and it is Critical.
>
> **Open: the isolator's host connector.** The only named candidate module presents a USB-B
> host receptacle where E-24 asks for USB-C. The interim resolution is a short USB-B-to-USB-C
> panel pigtail, WH-09, until a module with a USB-C host connector is qualified. This is a live
> non-conformance, not a settled design, and it changes nothing about the barrier itself.

### 5.5 Verification

| What | How | When | Who signs |
|---|---|---|---|
| Carrier has no host-side copper | Netlist inspection against design.py; copper-plot overlay of the keep-out on **all four layers**, inner layers included | Once per routed Gerber revision | Programme, countersigned by the safety reviewer |
| ≥ 8 mm creepage in the artwork | Measured from the artwork with the keep-out overlay (TST-EEG-004 section 14, the creepage and clearance type test) | Once per routed Gerber revision | First-article report |
| ≥ 8 mm slant path to MP-01 | The dimensioned MP-01 drawing and the 18 mm standoff of section 5.4 | Once per mechanical revision | Programme, seen by the safety reviewer |
| Module isolation rating | Vendor certificate and part marking photograph | T00, per module lot | Incoming inspection |
| No path host to applied part | T20: 500 V DC, 60 s, host-side shell/VBUS/D+/D− shorted against J14.1--J14.11 and J15--J17 shorted; ≥ 1 GΩ | Every unit | Test operator |
| 2.5 kV RMS type test | The module supplier's certificate, checked once at incoming inspection and never repeated per unit. There is no per-unit hipot on this product | T00, per module type | Safety reviewer accepts or rejects |
| DevKitC-1 receptacles blanked | Visual, before labelling; photograph in the unit record | Every unit | Assembly operator, first article by the reviewer |

**What the routing actually produced.** EEG-CAR-01 Rev B is routed on four layers, 150.0 ×
130.0 mm, with 3 745 track segments and 552 through vias, and each reference plane is one
continuous island per net on both In1.Cu and In2.Cu. **All 145 nets are fully connected**:
none is left unclosed and none is without copper. The smallest measured clearance is 0.260 mm
on F.Cu, 0.275 mm on B.Cu and 0.285 mm on the planes, against a 0.20 mm rule. The narrowest
conductor is 0.20 mm and the smallest plated hole is 0.30 mm. Copper stands 2.00 mm from every
non-plated hole and there are no zone crossings. No digital net enters the analogue zone. There
is exactly one AGND_REF-to-DGND bridge and one HARN_SHIELD-to-DGND bridge. There are no
duplicate copper segments and no duplicate via positions. The report's own line is
**"VIOLATIONS: 0 -- none. The board passes every rule listed above."**

**The isolation rule area is clean on all four copper layers.** That is said here because
`kicad/EEG-CAR-01_RevB_DRC_report.txt` says it: the report lists no isolation keep-out
violation, so no pour, plane, via, track or test point sits inside the 9.0 × 20.0 mm strip on
L1, L2, L3 or L4. It is not asserted from the fact that a rule area was drawn. The reviewer is
asked to read the report issued with the Gerbers that are actually released, because that
report and not this sentence is the evidence, and because the two inner layers cannot be
checked on a finished board.

**The board passes, and passing is not the same as reviewed.** The gate ECO-EEG-016 section 3
sets for releasing fabrication data is zero DRC violations, every net one connected copper
island, and both inner planes continuous under the analogue zone. All three are now met, so the
data in `kicad/` is **released for review under RFQ-EEG-002A**. It is **not released for
fabrication** and no board may be ordered from it: the routing was produced by the programme's
own tools, no human layout engineer has looked at it, and that review is what fabrication
release waits on. Nothing in this package has been manufactured or measured, so every figure
in this section is geometry read off the artwork, not something a board did.

**The router relaxed 169 connections to get there.** Thirty-six took a conductor narrower than
the 0.25 mm preferred width; 133 kept full width and took a reduced gap instead. Every one is
at or above the 0.20 mm minimum conductor and the 0.20 mm minimum gap, 0.35 mm on electrode
nets, which is why they are relaxations and not violations, and each is named pad to pad in the
DRC report. A board that closes at minimum geometry is not the same board as one that closes at
preferred geometry, even when every rule passes: it leaves less room for a fabricator's own
tolerances, and the thinnest places are the first ones to look at. The layout reviewer is asked
to read that list and say which of the 169 must change.

That is a safety matter and not only a layout one, for three reasons. First, this is still a
release gate sitting *before* the gate of section 7, though a smaller one than it was: the DRC
evidence, item 7 of the receipt checklist in 7.2, is now satisfied, but no board has been
fabricated, so no assembled unit exists, so item 17 cannot be satisfied and the review still
cannot start. Second, the routing can still change. A layout engineer reading the 169
relaxations may move copper, and several of them are on nets this pack reasons about -- AVSS,
AVDD, DVDD3V3, V5V, BIASOUT and SRB1 among them -- so the zoning, clearance and star-point
arguments of sections 4 and 5 are confirmed today by a checker and not by a person, and must be
re-checked against the routing finally released. Third, the 0.35 mm electrode clearance is a
risk control, and the same report that records zero violations records it as met everywhere on
the board -- by the automatic check, on an unreviewed routing, with the same qualification as
everything else here. This is carried as **SR-11** in section 10 and as item 4.16 of the
checklist.

---

## 6. Battery safety

### 6.1 The cell

| Property | Requirement | Reference |
|---|---|---|
| Type | Protected 18650, ≥ 3000 mAh, with an integral PCM giving over-charge, over-discharge and short-circuit protection | S-04, E-22, kit BOM item 11 |
| Reference parts | Panasonic NCR18650B protected (3400 mAh, 3.6 V nominal, **12.24 Wh**) or Samsung INR18650-35E in a protection holder (3500 mAh, **12.6 Wh**) | kit BOM |
| Transport classification | Under 20 Wh per cell and under 100 Wh per battery, so **UN3481, PI967 section II** when installed in equipment | S-09 |
| Documents required at incoming | UN 38.3 test summary; **IEC 62133-2 certificate**; SDS; lot code | T00, AVL-EEG-017 |
| Connector | J13, JST B2B-PH-K 2.00 mm, polarised, VBAT and DGND | design.py |
| Retention | The **HM-10** keyed cell carrier, behind the **HM-08** quarter-turn hatch; the cell cannot be inserted reversed | S-04, M-02 |
| Thermistor | **Not fitted. S-04's thermistor-monitored charging is not met** -- see 6.3 and SR-03 | S-04 |

HM-07 is the boom microphone arm and is not part of the battery compartment. Any text that
calls the hatch HM-07, or that merges the hatch and the carrier into one part number, is at
the package v1 numbering; PARTS-EEG-019 §3.1 is the register.

**No spare cell travels in the kit.** DSN-EEG-002 Rev E section 7 says a charged spare travels
in the case; the kit BOM Rev B carries one cell per kit and this pack rules that the BOM is
correct. A loose charged spare would move the shipment from PI967 (contained in equipment) to
PI966 (packed with equipment), with different packing and marking, and would put an unprotected
charged cell in foam next to a metal ratchet. DSN-EEG-002 Rev E must be corrected, and it has
not been: the shipped Rev E file is byte-identical to the one released in package v2.1, and
ECO-EEG-016 section 1.1 records that it was not re-issued in this correction round. **Until it
is, its section 7 is superseded on this point** by this section and by REG-EEG-012 Rev B
section 3.1, and nobody works from it for the spare cell.

### 6.2 Charge control

Charging is by a **separate, charge-only USB-C receptacle** on the panel, wired through a JST
PH pigtail to J24. No data conductor enters it. The path is F1 (Bourns MF-MSMF110-2 PTC,
1.1 A hold / 2.2 A trip) then D24 (Nexperia PESD5V0S2BT TVS) to VBUS_CHG at J12.3, with the
R84/R85 divider producing VBUS_DET at GPIO46. R84 is 100 kΩ and **R85 is 150 kΩ**, giving
5 × 150/250 = **3.00 V** at VBUS = 5 V, comfortably above the 2.48 V input-high threshold of a
3.3 V ESP32-S3 input; the 56 kΩ of the first cut gave 1.79 V and would not have asserted the
first S-01 interlock reliably, which is ECO-EEG-022. This receptacle is galvanically separate
from the isolated data USB-C on the ADuM4160 module: ECO-EEG-003 exists precisely because Rev A
tried to make one connector do both, which cannot be reconciled with S-03.

The interlock (S-01) has two mechanisms:

1. firmware refuses `CMD_START_SESSION` while VBUS_DET is high, with a defined ACK code;
2. CHG_CE (GPIO47, at J12.4) holds the charger disabled for the whole of a session.

Both are verified per unit at T4 and T21. **Both are firmware.** There is no hardware gate
that would keep the charger off if the firmware misbehaved, and section 3 records that as H-08
with a decision owed at SR-02. The reviewer must rule on whether a firmware-only interlock is
acceptable for a device used unsupervised, or whether an independent hardware inhibit -- a
two-input gate between VBUS_DET, a hardware session-active latch and CHG_CE -- is required
before Phase 2. It is two parts on a board that has not been fabricated.
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

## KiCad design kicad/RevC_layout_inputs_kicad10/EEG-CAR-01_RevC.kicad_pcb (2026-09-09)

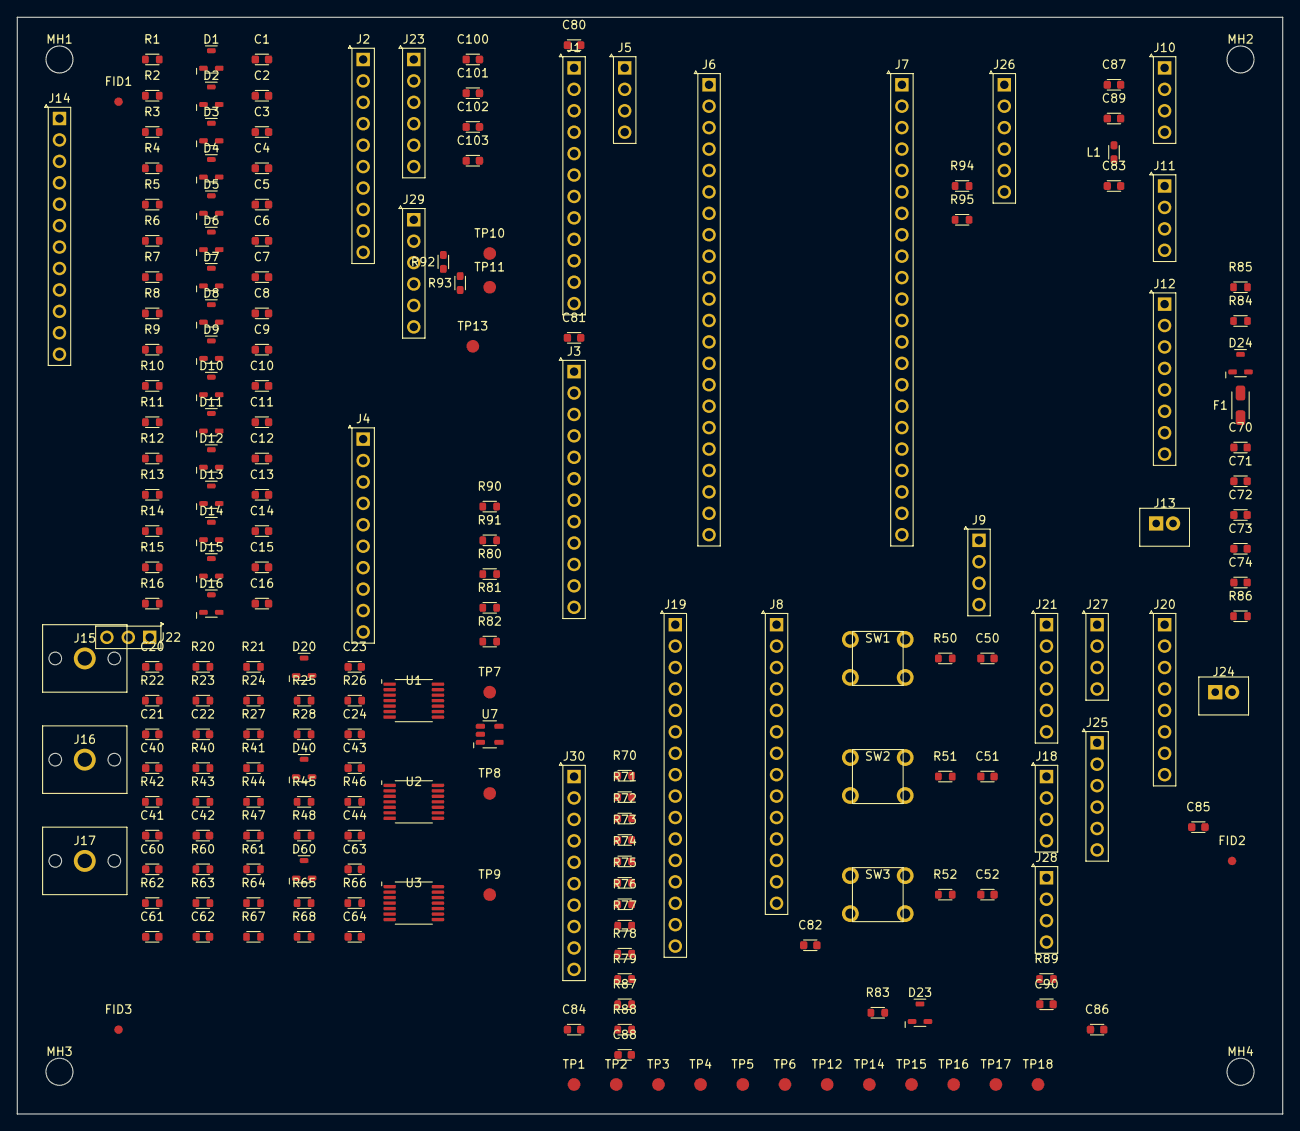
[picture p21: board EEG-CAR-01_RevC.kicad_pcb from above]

Board: 4 copper layers, 150.0 x 130.0 mm, 211 parts (0 on the bottom side), 145 nets, no tracks yet.

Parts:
C1, C2, C3, C4, C5, C6, C7, C8, C9, C10, C11, C12, C13, C14, C15, C16, C21, C41, C61: 10n C0G 50V; C_0603_1608Metric
C20, C40, C60, C70, C71, C72, C73, C74, C89, C90, C100, C101: 10u X5R 16V; C_0603_1608Metric
C22, C42, C62: 22n C0G 50V; C_0603_1608Metric
C23, C24, C43, C44, C50, C51, C52, C63, C64, C80, C81, C82, C83, C84, C85, C86, C87, C88: 100n X7R 25V; C_0603_1608Metric
C102, C103: 100n X7R 50V; C_0603_1608Metric
D1, D2, D3, D4, D5, D6, D7, D8, D9, D10, D11, D12, D13, D14, D15, D16, D23: BAV99; SOT-23
D20, D40, D60: BAT54S; SOT-23
D24: PESD5V0S2BT; SOT-23
F1: PTC 1.1 A hold / 2.2 A trip; R_1206_3216Metric
FID1, FID2, FID3: global fiducial; Fiducial_1mm_Mask3mm
J1: ADS1299 module #1 digital; PinSocket_1x12_P2.54mm_Vertical
J2: ADS1299 module #1 analogue signals; PinSocket_1x10_P2.54mm_Vertical
J3: ADS1299 module #2 digital; PinSocket_1x12_P2.54mm_Vertical
J4: ADS1299 module #2 analogue signals; PinSocket_1x10_P2.54mm_Vertical
J5: ADS #1 DAISY_IN / CLKOUT stub; PinSocket_1x04_P2.54mm_Vertical
J6: ESP32-S3-DevKitC-1 row A; PinSocket_1x22_P2.54mm_Vertical
J7: ESP32-S3-DevKitC-1 row B; PinSocket_1x22_P2.54mm_Vertical
J8: ES8388 codec module; PinSocket_1x14_P2.54mm_Vertical
J9: Codec microphone feeds; PinSocket_1x04_P2.54mm_Vertical
J10: ADuM4160 USB isolator, device side; PinSocket_1x04_P2.54mm_Vertical
J11: ATECC608B breakout; PinSocket_1x04_P2.54mm_Vertical
J12: Charger + fuel gauge module; PinSocket_1x08_P2.54mm_Vertical
J13: 18650 protected cell; JST_PH_B2B-PH-K_1x02_P2.00mm_Vertical
J14: Helmet harness -- electrodes (12-way screened); PinSocket_1x12_P2.54mm_Vertical
J15: DIN 42802 EMG1 cheek; DIN42802_1p5mm_Socket
J16: DIN 42802 EMG2 submental; DIN42802_1p5mm_Socket
J17: DIN 42802 EMG3 laryngeal; DIN42802_1p5mm_Socket
J18: Boom microphone pigtail (TRRS); PinSocket_1x04_P2.54mm_Vertical
J19: 74HC595 contact-light driver; PinSocket_1x16_P2.54mm_Vertical
J20: microSD breakout, SDMMC 1-bit; PinSocket_1x08_P2.54mm_Vertical
J21: Boom-mic preamp module (part not settled, E-14); PinSocket_1x06_P2.54mm_Vertical
J22: EOG / spare electrode header; PinSocket_1x03_P2.54mm_Vertical
J23: ADS1299 module #1 analogue rails; PinSocket_1x06_P2.54mm_Vertical
J24: Charge input from the panel USB-C; JST_PH_B2B-PH-K_1x02_P2.00mm_Vertical
J25: Buck-boost module, TPS63020 class; PinSocket_1x06_P2.54mm_Vertical
J26: Debug / programming header; PinSocket_1x06_P2.54mm_Vertical
J27: Headphone jack pigtail; PinSocket_1x04_P2.54mm_Vertical
J28: Room microphone module; PinSocket_1x04_P2.54mm_Vertical
J29: ADS1299 module #2 analogue rails; PinSocket_1x06_P2.54mm_Vertical
J30: Helmet harness -- contact lights (10-way); PinSocket_1x10_P2.54mm_Vertical
L1: 600R at 100 MHz, 500 mA; L_0603_1608Metric
MH1, MH2, MH3, MH4: M3 x 3.2 mm NPTH; MountingHole_3.2mm_M3
R1, R2, R3, R4, R5, R6, R7, R8, R9, R10, R11, R12, R13, R14, R15, R16: 68k 0.1% 25ppm; R_0603_1608Metric
R20, R21, R23, R24, R40, R41, R43, R44, R60, R61, R63, R64: 10k 0.1%; R_0603_1608Metric
R22, R42, R62: 4k99 0.1%; R_0603_1608Metric
R25, R26, R45, R46, R65, R66: 215k 0.1%; R_0603_1608Metric
R27, R47, R67: 22k 0.1%; R_0603_1608Metric
R28, R48, R68: 2k2 0.1%; R_0603_1608Metric
R50, R51, R52, R81, R83, R88: 10k 1%; R_0603_1608Metric
R70, R71, R72, R73, R74, R75, R76, R77: 1k 1%; R_0603_1608Metric
R78, R79, R87, R90, R91, R92, R93: 0R; R_0603_1608Metric
R80: 470k 1%; R_0603_1608Metric
R82: 1M 1%; R_0603_1608Metric
R84, R86: 100k 1%; R_0603_1608Metric
R85: 150k 1%; R_0603_1608Metric
R89: 2k2 1% -- DNP; R_0603_1608Metric
R94, R95: 4k7 1%; R_0603_1608Metric
SW1: BTN_A response (green); SW_PUSH_6mm_H7.3mm
SW2: BTN_B response (blue); SW_PUSH_6mm_H7.3mm
SW3: BTN_STOP (red); SW_PUSH_6mm_H7.3mm
TP1: SCLK; TestPoint_Pad_D1.5mm
TP2: MOSI; TestPoint_Pad_D1.5mm
TP3: MISO; TestPoint_Pad_D1.5mm
TP4: DRDY; TestPoint_Pad_D1.5mm
TP5: I2S_BCLK; TestPoint_Pad_D1.5mm
TP6: I2S_LRCK; TestPoint_Pad_D1.5mm
TP7: ENV_STIM; TestPoint_Pad_D1.5mm
TP8: ENV_VOICE; TestPoint_Pad_D1.5mm
TP9: ENV_ROOM; TestPoint_Pad_D1.5mm
TP10: AVDD; TestPoint_Pad_D1.5mm
TP11: AVSS; TestPoint_Pad_D1.5mm
TP12: DVDD3V3; TestPoint_Pad_D1.5mm
TP13: AGND_REF; TestPoint_Pad_D1.5mm
TP14: DGND; TestPoint_Pad_D1.5mm
TP15: VSYS; TestPoint_Pad_D1.5mm
TP16: V5V; TestPoint_Pad_D1.5mm
TP17: NC_DRDY2; TestPoint_Pad_D1.5mm
TP18: CLK_ADS; TestPoint_Pad_D1.5mm
U1, U2, U3: OPA4376AIPW; TSSOP-14_4.4x5mm_P0.65mm
U7: TLV3201AIDBV; SOT-23-5

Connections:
AGND_REF: C1.2, C2.2, C3.2, C4.2, C5.2, C6.2, C7.2, C8.2, C9.2, C10.2, C11.2, C12.2, C13.2, C14.2, C15.2, C16.2, C21.2, C23.2, C24.2, C41.2, C43.2, C44.2, C61.2, C63.2, C64.2, C100.2, C101.2, C102.2, C103.2, J22.2, J23.4, J29.4, R28.2, R48.2, R68.2, R81.2, R90.1, TP13.1, U1.3, U1.5, U2.3, U2.5, U3.3, U3.5
AVDD: C23.1, C43.1, C63.1, C100.1, C102.1, D1.2, D2.2, D3.2, D4.2, D5.2, D6.2, D7.2, D8.2, D9.2, D10.2, D11.2, D12.2, D13.2, D14.2, D15.2, D16.2, J23.1, J23.5, R80.1, R92.2, TP10.1, U1.4, U2.4, U3.4, U7.5
AVDD2: J29.1, J29.5, R92.1
AVSS: C24.1, C44.1, C64.1, C101.1, C103.1, D1.1, D2.1, D3.1, D4.1, D5.1, D6.1, D7.1, D8.1, D9.1, D10.1, D11.1, D12.1, D13.1, D14.1, D15.1, D16.1, J23.2, J23.6, R93.2, TP11.1, U1.11, U2.11, U3.11, U7.2
AVSS2: J29.2, J29.6, R93.1
BIASIN: J23.3, J29.3
BIASOUT: C11.1, D11.3, J2.10, R11.2
BIAS_EL: J14.11, R11.1
BOOST_EN: J25.5, R86.2
BTN_A: C50.1, J6.4, R50.1, SW1.1
BTN_B: C51.1, J6.5, R51.1, SW2.1
BTN_STOP: C52.1, J6.6, R52.1, SW3.1
CHG_CE: J7.17, J12.4
CLK_ADS: J1.10, J3.10, J5.2, TP18.1
CMP_RAW: R82.1, R83.1, U7.1
CS: J1.7, J3.7, J6.16
DAISY: J3.5, J5.1
DGND: C50.2, C51.2, C52.2, C70.2, C71.2, C72.2, C73.2, C74.2, C80.2, C81.2, C82.2, C83.2, C84.2, C85.2, C86.2, C87.2, C88.2, C89.2, C90.2, D23.1, D24.2, D24.3, J1.2, J1.12, J3.2, J3.12, J5.3, J5.4, J6.22, J7.1, J7.21, J7.22, J8.2, J9.3, J10.4, J11.2, J12.2, J13.2, J18.2, J18.3, J18.4, J19.2, J20.2, J20.6, J20.7, J20.8, J21.2, J21.6, J24.2, J25.2, J25.4, J26.2, J28.2, R79.2, R85.2, R87.2, R90.2, R91.2, SW1.2, SW2.2, SW3.2, TP14.1
DRDY: J1.6, J6.20, TP4.1
DVDD3V3: C74.1, C80.1, C81.1, C82.1, C83.1, C84.1, C85.1, C86.1, C90.1, D23.2, J1.1, J3.1, J6.1, J6.2, J8.1, J11.1, J19.1, J20.1, J21.1, J26.1, J28.1, L1.1, R50.2, R51.2, R52.2, R88.2, R89.1, R94.2, R95.2, TP12.1
EMG1: C12.1, D12.3, J4.1, R12.2
EMG2: C13.1, D13.3, J4.2, R13.2
EMG3: C14.1, D14.3, J4.3, R14.2
EMGIN1: J15.1, R12.1
EMGIN2: J16.1, R13.1
EMGIN3: J17.1, R14.1
ENV1_ABS: R24.2, R25.1, U1.7
ENV1_AC: C20.2, R20.1, R23.1
ENV1_DIV: R27.2, R28.1, U1.12
ENV1_FLT: C22.2, R27.1, U1.8, U1.9
ENV1_HW: D20.1, R21.1, R22.1
ENV1_INM: D20.2, R20.2, R21.2, U1.2
ENV1_INP: C21.1, R26.2, U1.10
ENV1_MID: C22.1, R25.2, R26.1
ENV1_ROUT: D20.3, U1.1
ENV1_SUM: R22.2, R23.2, R24.1, U1.6
ENV2_ABS: R44.2, R45.1, U2.7
ENV2_AC: C40.2, R40.1, R43.1
ENV2_DIV: R47.2, R48.1, U2.12
ENV2_FLT: C42.2, R47.1, U2.8, U2.9
ENV2_HW: D40.1, R41.1, R42.1
ENV2_INM: D40.2, R40.2, R41.2, U2.2
ENV2_INP: C41.1, R46.2, U2.10
ENV2_MID: C42.1, R45.2, R46.1
ENV2_ROUT: D40.3, U2.1
ENV2_SUM: R42.2, R43.2, R44.1, U2.6
ENV3_ABS: R64.2, R65.1, U3.7
ENV3_AC: C60.2, R60.1, R63.1
ENV3_DIV: R67.2, R68.1, U3.12
ENV3_FLT: C62.2, R67.1, U3.8, U3.9
ENV3_HW: D60.1, R61.1, R62.1
ENV3_INM: D60.2, R60.2, R61.2, U3.2
ENV3_INP: C61.1, R66.2, U3.10
ENV3_MID: C62.1, R65.2, R66.1
ENV3_ROUT: D60.3, U3.1
ENV3_SUM: R62.2, R63.2, R64.1, U3.6
ENV_CMP: D23.3, J6.13, R83.2
ENV_ROOM: J4.6, TP9.1, U3.13, U3.14
ENV_STIM: J4.4, R82.2, TP7.1, U1.13, U1.14, U7.3
ENV_THR: R80.2, R81.1, U7.4
ENV_VOICE: J4.5, TP8.1, U2.13, U2.14
EOGIN1: J22.1, R15.1
EOGIN2: J22.3, R16.1
E_C3: J14.4, R4.1
E_C4: J14.5, R5.1
E_Cz: J14.2, R2.1
E_F7: J14.8, R8.1
E_Fz: J14.1, R1.1
E_Pz: J14.3, R3.1
E_T7: J14.6, R6.1
E_T8: J14.7, R7.1
HARN_SHIELD: J14.12, R91.1
HP_GND: J8.13, J27.3
HP_L: J8.11, J27.1
HP_R: J8.12, J27.2
HP_TAP: C20.1, J8.10
I2S_BCLK: J6.11, J8.4, TP5.1
I2S_DIN: J6.7, J8.6
I2S_DOUT: J6.15, J8.7
I2S_LRCK: J6.12, J8.5, TP6.1
I2S_MCLK: J6.10, J8.3
IN1: C1.1, D1.3, J2.1, R1.2
IN2: C2.1, D2.3, J2.2, R2.2
IN3: C3.1, D3.3, J2.3, R3.2
IN4: C4.1, D4.3, J2.4, R4.2
IN5: C5.1, D5.3, J2.5, R5.2
IN6: C6.1, D6.3, J2.6, R6.2
IN7: C7.1, D7.3, J2.7, R7.2
IN8: C8.1, D8.3, J2.8, R8.2
LED1: J30.1, R70.2
LED2: J30.2, R71.2
LED3: J30.3, R72.2
LED4: J30.4, R73.2
LED5: J30.5, R74.2
LED6: J30.6, R75.2
LED7: J30.7, R76.2
LED8: J30.8, R77.2
LED_GND: J30.10, R79.1
LED_MR: C88.1, J19.7, R88.1
LED_OE: J19.6, R87.1
LED_PWM: J7.16, R78.1
LED_SR_CLK: J7.6, J19.4
LED_SR_DATA: J7.7, J19.3
LED_SR_LATCH: J7.14, J19.5
LED_V: J30.9, R78.2
MIC_MUTE: J7.18, J9.4, J28.4
MISO: J1.5, J6.19, TP3.1
MOSI: J1.4, J3.4, J6.17, TP2.1
NC_DRDY2: J3.6, TP17.1
REF_L: J14.9, R9.1
REF_R: J14.10, R10.1
RESET: J1.9, J3.9, J6.9
RESET_EN: J6.3, J26.5
ROOM_PRE: C60.1, J9.2, J28.3
SCL: J7.5, J8.9, J11.4, J12.6, R95.1
SCLK: J1.3, J3.3, J6.18, TP1.1
SDA: J7.4, J8.8, J11.3, J12.5, R94.1
SD_CLK: J7.9, J20.3
SD_CMD: J7.10, J20.4
SD_D0: J7.8, J20.5
SPARE1: C15.1, D15.3, J4.7, R15.2
SPARE2: C16.1, D16.3, J4.8, R16.2
SRB1: C9.1, C10.1, D9.3, D10.3, J2.9, J4.9, R9.2, R10.2
SR_Q0: J19.8, R70.1
SR_Q1: J19.9, R71.1
SR_Q2: J19.10, R72.1
SR_Q3: J19.11, R73.1
SR_Q4: J19.12, R74.1
SR_Q5: J19.13, R75.1
SR_Q6: J19.14, R76.1
SR_Q7: J19.15, R77.1
START: J1.8, J3.8, J6.8
UART_RX: J7.3, J26.4
UART_TX: J7.2, J26.3
USB_DN: J7.20, J10.2
USB_DP: J7.19, J10.3
V5V: C72.1, C73.1, J1.11, J3.11, J6.21, J8.14, J25.3, TP16.1
VBAT: J12.1, J13.1
VBUS_CHG: D24.1, F1.2, J12.3, R84.1
VBUS_DET: J6.14, R84.2, R85.1
VBUS_IN: F1.1, J24.1
VDD_ISO: C87.1, C89.1, J10.1, L1.2
VOICE_PRE: C40.1, J9.1, J21.3
VOICE_RAW: J18.1, J21.4, R89.2
VSYS: C70.1, C71.1, J12.7, J25.1, R86.1, TP15.1

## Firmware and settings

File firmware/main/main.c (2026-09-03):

/*
 * FW-EEG-001  —  TI One Voice EEG field kit firmware (ESP32-S3, ESP-IDF 5.x + TinyUSB)
 * Status: reference implementation written against RFQ-EEG-001 Rev B section 5 and
 * DSN-EEG-003. Compiles against ESP-IDF 5.2 API names; NOT yet run on hardware.
 * Licence: MIT (firmware). Hardware is CC BY-SA 4.0.
 *
 * What this file implements
 *  - ADS1299 x2 daisy-chain bring-up, 250/500/1000 Hz, gain per channel, lead-off on ch1-8
 *  - DRDY ISR: the ONLY place the 32-bit sample counter increments (E-19)
 *  - Sample = 16 x int24 + 16-bit aux (buttons, comparator, lead-off summary, charger, SD ok)
 *  - Frames: DATA / STATUS / EVENT / GAP / SIGNATURE / CMD_ACK, COBS-encoded, CRC-32, 0x00 delimiter
 *  - Ring buffer >= 3 min at 1 kHz in PSRAM, sequence numbers, retransmit by range, GAP on overflow
 *  - microSD append of the identical frame stream (authoritative copy)
 *  - USB composite: CDC-ACM (WebSerial) + vendor bulk (WebUSB), BOS with WebUSB platform
 *    descriptor and Microsoft OS 2.0 descriptor (WinUSB auto-bind), iSerial = the unit
 *    serial TIOV-B-nnnn (RFQ F-04; RUL-EEG-021 section B). NOT the ATECC factory serial.
 *  - Command channel (F-10) and timing self-test (F-21)
 *  - Contact lights via 74HC595 from lead-off status; forced OFF during recording blocks (E-27)
 *  - Radio never initialised. No Wi-Fi / BT code path exists in this build.
 */
#include <string.h>
#include <stdint.h>
#include <stdbool.h>
#include "freertos/FreeRTOS.h"
#include "freertos/task.h"
#include "freertos/ringbuf.h"
#include "driver/spi_master.h"
#include "driver/gpio.h"
#include "esp_timer.h"
#include "esp_log.h"
#include "esp_heap_caps.h"
#include "tinyusb.h"
#include "tusb.h"

static const char *TAG = "eegkit";

/* ------------------------------------------------------------------ pins
 * FW-D12 CLOSED.  This file used to carry its own copy of the pin map, and that copy was
 * the Rev A one: it drove the contact-light shift register on GPIO35/36/37, which are the
 * OCTAL PSRAM bus of the -N16R8.  main() called gpio_set_direction() on all three at boot
 * and lights_write() toggled them, so a unit flashed with it would have torn down the
 * PSRAM the ring buffer lives in.
 *
 * The generated header is now the only pin map.  It comes from design.py, so the firmware
 * and the board cannot disagree; regenerate it rather than editing it.  The aliases below
 * exist only so the rest of this file keeps its original names.
 */
#include "board_pins.h"
/* IRAM_ATTR comes from esp_attr.h.  main.c used it at drdy_isr() and relied on some other
   header dragging it in; ESP-IDF happens to, but nothing here guaranteed it. */
#include "esp_attr.h"
/* The peripheral API implemented in drivers.c.  Without this the calls to sd_free_mb(),
   unit_serial_into() and atecc_serial_into() were implicit declarations -- an error in
   C99 and later, and a silent int-return assumption where a compiler allows it. */
#include "drivers.h"

/* drivers.c */
esp_err_t drv_init_all(void);
void      drv_sd_flush(void);
esp_err_t drv_sd_open_session(const char *name);

#define PIN_CS      PIN_ADS_CS
#define PIN_MOSI    PIN_ADS_MOSI
#define PIN_SCLK    PIN_ADS_SCLK
#define PIN_MISO    PIN_ADS_MISO
#define PIN_DRDY    PIN_ADS_DRDY
#define PIN_START   PIN_ADS_START
#define PIN_RESET   PIN_ADS_RESET
#define PIN_LED_PWM PIN_LED_V

/* ------------------------------------------------------------------ ADS1299 registers/opcodes */
#define ADS_WAKEUP 0x02
#define ADS_STANDBY 0x04
#define ADS_RESET 0x06
#define ADS_START 0x08
#define ADS_STOP  0x0A
#define ADS_RDATAC 0x10
#define ADS_SDATAC 0x11
#define ADS_RREG 0x20
#define ADS_WREG 0x40
#define REG_CONFIG1 0x01
#define REG_CONFIG2 0x02
#define REG_CONFIG3 0x03
#define REG_LOFF    0x04
#define REG_CH1SET  0x05
#define REG_BIAS_SENSP 0x0D
#define REG_BIAS_SENSN 0x0E
#define REG_LOFF_SENSP 0x0F
#define REG_LOFF_STATP 0x12
#define REG_MISC1   0x15
#define REG_CONFIG4 0x17

#define N_CH 16
#define N_DEV 2
#define FRAME_SAMPLES_MAX 20
#define SAMPLE_BYTES (N_CH*3+2)                 /* 50 */
/* FW-D13 CLOSED.  This was 12 MiB on a part with 8 MiB of PSRAM: the allocation
   returned NULL and the first DATA frame asserted inside xRingbufferSend.  6 MiB is
   126 s of raw samples at 1 kHz (124 s counted over the framed stream), against the
   90 s that F-06 asks for as relaxed by ECO-EEG-025. */
#define RING_BYTES (6*1024*1024)                /* 6,291,456 B -- 126 s @ 1 kHz */

static spi_device_handle_t ads;
static volatile uint32_t g_sample_index = 0;    /* monotonic; incremented ONLY in DRDY ISR */
static volatile uint16_t g_seq = 0;
static uint16_t g_rate_code = 1;                /* 0=250,1=500,2=1000 Hz  (fleet default 500) */
static bool g_recording = false;
static bool g_lights_enabled = true;
static uint16_t g_loff_bits = 0;                /* lead-off summary for ch1-8 */
static volatile uint8_t g_loff_p = 0;           /* LOFF_STATP, ch1-8, at the live threshold */
static volatile uint8_t g_loff_n = 0;           /* LOFF_STATN, ch1-8 -- see the note below */
/* The two latched comparator results the contact lights are built from (FW-D17).  Each
   holds LOFF_STATP as read while the corresponding COMP_TH was programmed. */
static volatile uint8_t g_loff_sens = 0;        /* tripped at the SENSITIVE threshold */
static volatile uint8_t g_loff_insens = 0;      /* tripped at the INSENSITIVE threshold */
static volatile uint8_t g_lights_force = 0;     /* CMD_LIGHTS mode 2/3/4: 0 = automatic */
static volatile uint8_t g_lights_force_mask = 0xFF;
static RingbufHandle_t rb;                      /* PSRAM ring of DATA frames (for backfill) */

/* ------------------------------------------------------------------ CRC-32 (IEEE) */
static uint32_t crc32(const uint8_t *d, size_t n) {
    uint32_t c = 0xFFFFFFFFu;
    for (size_t i = 0; i < n; i++) { c ^= d[i]; for (int k = 0; k < 8; k++) c = (c >> 1) ^ (0xEDB88320u & (0u - (c & 1))); }
    return ~c;
}
/* ------------------------------------------------------------------ COBS encode: out must hold n + n/254 + 2 */
static size_t cobs_encode(const uint8_t *in, size_t n, uint8_t *out) {
    size_t ri = 0, wi = 1, code_i = 0; uint8_t code = 1;
    while (ri < n) {
        if (in[ri] == 0) { out[code_i] = code; code = 1; code_i = wi++; ri++; }
        else { out[wi++] = in[ri++]; if (++code == 0xFF) { out[code_i] = code; code = 1; code_i = wi++; } }
    }
    out[code_i] = code; out[wi++] = 0x00; return wi;
}

/* ------------------------------------------------------------------ frame types and header (RFQ 5.2) */
enum { FT_DATA = 1, FT_STATUS = 2, FT_EVENT = 3, FT_GAP = 4, FT_SIGNATURE = 5, FT_CMD_ACK = 6,
       /* host -> device.  FW-EEG-001 section 5.2 and TOOL-EEG-022; the host stamps this in
          header byte 1 and the device had no name for it, so it never checked it. */
       FT_CMD = 16 };
#pragma pack(push,1)
/* FW-D19.  This used to be memcpy'd onto the wire with sizeof(), and sizeof() is 12,
   not 10: the struct is tail-padded to its 4-byte alignment, so two padding bytes landed
   between the header and the payload and every host parser written to FW-EEG-001 section
   5.1 -- including this package's own tools/verify_stream.py, which unpacks "<BBHIBB" --
   misparsed every frame by two bytes.
   The header is now serialised field by field into a fixed 10-byte layout.  A wire format
   must never be a struct copy: the layout is a contract with other people's software, not
   a detail of how this compiler happens to lay out memory. */
#define FRAME_HDR_BYTES 10
typedef struct { uint8_t version, type; uint16_t seq; uint32_t first_sample; uint8_t rate_code, n_samples; } frame_hdr_t;

static size_t frame_hdr_put(uint8_t *o, const frame_hdr_t *h) {
    o[0] = h->version;
    o[1] = h->type;
    o[2] = (uint8_t)(h->seq & 0xFF);
    o[3] = (uint8_t)(h->seq >> 8);
    o[4] = (uint8_t)(h->first_sample & 0xFF);
    o[5] = (uint8_t)((h->first_sample >> 8) & 0xFF);
    o[6] = (uint8_t)((h->first_sample >> 16) & 0xFF);
    o[7] = (uint8_t)((h->first_sample >> 24) & 0xFF);
    o[8] = h->rate_code;
    o[9] = h->n_samples;
    return FRAME_HDR_BYTES;
}
_Static_assert(FRAME_HDR_BYTES == 10, "FW-EEG-001 section 5.1 fixes the header at 10 bytes");
#pragma pack(pop)
#define PROTO_VERSION 1

static uint8_t txbuf[2 + sizeof(frame_hdr_t) + FRAME_SAMPLES_MAX * SAMPLE_BYTES + 4 + 64];
static uint8_t cobsbuf[sizeof(txbuf) + sizeof(txbuf) / 254 + 2];

static void frame_emit(uint8_t type, uint32_t first_sample, uint8_t n_samples, const uint8_t *payload, size_t plen) {
    frame_hdr_t h = { PROTO_VERSION, type, g_seq++, first_sample, (uint8_t)g_rate_code, n_samples };
    size_t o = frame_hdr_put(txbuf, &h);   /* NOT sizeof h -- see FW-D19 */
    memcpy(txbuf + o, payload, plen); o += plen;
    uint32_t c = crc32(txbuf, o); memcpy(txbuf + o, &c, 4); o += 4;
    size_t enc = cobs_encode(txbuf, o, cobsbuf);
    /* identical bytes to USB (both interfaces if open), ring buffer and SD */
    if (tud_cdc_connected()) { tud_cdc_write(cobsbuf, enc); tud_cdc_write_flush(); }
    if (tud_vendor_mounted()) tud_vendor_write(cobsbuf, enc), tud_vendor_write_flush();
    if (type == FT_DATA) {
        if (xRingbufferSend(rb, cobsbuf, enc, 0) != pdTRUE) {
            /* overflow: drop oldest until it fits, then announce the gap (F-07) */
            size_t sz; void *old;
            while ((old = xRingbufferReceive(rb, &sz, 0)) != NULL) { vRingbufferReturnItem(rb, old); if (xRingbufferSend(rb, cobsbuf, enc, 0) == pdTRUE) break; }
        }
    }
    extern void sd_append(const uint8_t *, size_t); sd_append(cobsbuf, enc);
}

/* ------------------------------------------------------------------ ADS1299 low level */
static void ads_cmd(uint8_t c) { spi_transaction_t t = { .length = 8, .tx_buffer = &c }; spi_device_polling_transmit(ads, &t); }
static void ads_wreg_all(uint8_t reg, uint8_t val) {
    /* daisy-chain: write goes to both devices in sequence (device 2 first on the chain) */
    uint8_t buf[2 + N_DEV] = { ADS_WREG | reg, 0 };
    for (int i = 0; i < N_DEV; i++) buf[2 + i] = val;
    spi_transaction_t t = { .length = 8 * sizeof buf, .tx_buffer = buf }; spi_device_polling_transmit(ads, &t);
}
/* LOFF (0x04) = COMP_TH[7:5] | reserved[4] | ILEAD_OFF[3:2] | FLEAD_OFF[1:0].
   ILEAD_OFF 00 = 6 nA and FLEAD_OFF 11 = AC at fDR/4 are what ads_init() sets and what
   E-06 asks for; only COMP_TH moves.  COMP_TH is the fraction of supply the lead-off
   voltage must exceed for the comparator to trip, so a HIGHER percentage needs a HIGHER
   electrode impedance to trip: 70 % is the sensitive end, 95 % the insensitive one. */
#define LOFF_BASE        0x03                   /* ILEAD_OFF = 6 nA, FLEAD_OFF = AC fDR/4 */
#define LOFF_TH_SENS     (0xE0 | LOFF_BASE)     /* COMP_TH 111 = 70 % -- trips when marginal */
#define LOFF_TH_INSENS   (0x00 | LOFF_BASE)     /* COMP_TH 000 = 95 % -- trips only when off */

/* Move the lead-off comparator threshold.  A register write is only accepted outside
   RDATAC, so the continuous read is stopped and restarted around it.  This is called
   only from lights_task(), which never runs while g_recording is set, so no sample
   stream is ever interrupted by it. */
static void ads_set_loff_threshold(uint8_t loff_reg) {
    ads_cmd(ADS_SDATAC);
    ads_wreg_all(REG_LOFF, loff_reg);
    ads_cmd(ADS_RDATAC);
}

static void ads_set_rate(uint16_t code) {
    /* CONFIG1: 0x90 | DR ; DR: 110=250, 101=500, 100=1000 SPS ; bit6 DAISY_EN=0 (daisy on) */
    uint8_t dr = (code == 0) ? 0x06 : (code == 1) ? 0x05 : 0x04;
    ads_wreg_all(REG_CONFIG1, 0x90 | dr); g_rate_code = code;
}
static void ads_init(void) {
    spi_bus_config_t bus = { .mosi_io_num = PIN_MOSI, .miso_io_num = PIN_MISO, .sclk_io_num = PIN_SCLK, .quadwp_io_num = -1, .quadhd_io_num = -1, .max_transfer_sz = 64 };
    spi_bus_initialize(SPI2_HOST, &bus, SPI_DMA_CH_AUTO);
    spi_device_interface_config_t dev = { .clock_speed_hz = 4000000, .mode = 1, .spics_io_num = PIN_CS, .queue_size = 4 };
    spi_bus_add_device(SPI2_HOST, &dev, &ads);
    gpio_set_direction(PIN_RESET, GPIO_MODE_OUTPUT); gpio_set_direction(PIN_START, GPIO_MODE_OUTPUT);
    gpio_set_level(PIN_START, 0); gpio_set_level(PIN_RESET, 0); vTaskDelay(pdMS_TO_TICKS(2)); gpio_set_level(PIN_RESET, 1); vTaskDelay(pdMS_TO_TICKS(2));
    ads_cmd(ADS_SDATAC);
    ads_wreg_all(REG_CONFIG3, 0xEC);           /* internal ref, BIAS buffer + measure, BIASREF int */
    ads_wreg_all(REG_CONFIG2, 0xC0);           /* test signal off */
    ads_set_rate(1);
    /* device 1: EEG ch1-8 gain 24 normal ; device 2: ch1-3 EMG gain 12, ch4-6 envelope gain 1, ch7-8 gain 24 */
    for (int ch = 0; ch < 8; ch++) {
        uint8_t buf[2 + N_DEV] = { ADS_WREG | (REG_CH1SET + ch), 0 };
        buf[2] = (ch < 3) ? 0x50 : (ch < 6) ? 0x00 : 0x60;    /* device 2 (first on chain): 0x50 g12, 0x00 g1, 0x60 g24 */
        buf[3] = 0x60;                                          /* device 1 (EEG): gain 24 */
        spi_transaction_t t = { .length = 8 * sizeof buf, .tx_buffer = buf }; spi_device_polling_transmit(ads, &t);
    }
    /* lead-off: device 1 all 8 channels, AC 7.8 Hz excitation, 6 nA (E-06); device 2 none */
    { uint8_t b1[2 + N_DEV] = { ADS_WREG | REG_LOFF, 0, 0x00, 0x03 }; spi_transaction_t t = { .length = 32, .tx_buffer = b1 }; spi_device_polling_transmit(ads, &t); }
    { uint8_t b2[2 + N_DEV] = { ADS_WREG | REG_LOFF_SENSP, 0, 0x00, 0xFF }; spi_transaction_t t = { .length = 32, .tx_buffer = b2 }; spi_device_polling_transmit(ads, &t); }
    { uint8_t b3[2 + N_DEV] = { ADS_WREG | REG_BIAS_SENSP, 0, 0x00, 0xFF }; spi_transaction_t t = { .length = 32, .tx_buffer = b3 }; spi_device_polling_transmit(ads, &t); }
    ads_wreg_all(REG_MISC1, 0x20);             /* SRB1 as reference for all channels */
    ads_cmd(ADS_RDATAC);
}

/* ------------------------------------------------------------------ DRDY ISR -> sample task */
static TaskHandle_t sample_task_h;
/* FW-D08 CLOSED.  The comparator bit used to be sampled in the task, which put an
   unbounded scheduling delay between the stimulus edge and the sample it was attributed
   to; E-12 exists to make that attribution exact.  It is latched here, in the ISR, at the
   instant the converter says the sample is ready, and carried per sample.
   g_onset_* are read by envelope_onset_after() in drivers.c. */
volatile uint32_t g_onset_sample;
volatile uint8_t  g_onset_valid;
static volatile uint8_t g_env_latched;
static volatile uint8_t g_env_prev;

static void IRAM_ATTR drdy_isr(void *arg) {
    g_sample_index++;                          /* the only timeline in the system (E-19) */
    uint8_t env = gpio_get_level(PIN_ENV_CMP) ? 1 : 0;
    g_env_latched = env;
    if (env && !g_env_prev) {                  /* rising edge = stimulus onset */
        g_onset_sample = g_sample_index;
        g_onset_valid = 1;
    }
    g_env_prev = env;
    BaseType_t hp = pdFALSE; vTaskNotifyGiveFromISR(sample_task_h, &hp); if (hp) portYIELD_FROM_ISR();
}
static uint16_t aux_bits(void) {
    uint16_t a = 0;
    if (!gpio_get_level(PIN_BTN_A)) a |= 1 << 0;
    if (!gpio_get_level(PIN_BTN_B)) a |= 1 << 1;
    if (!gpio_get_level(PIN_BTN_STOP)) a |= 1 << 2;
    if (g_env_latched) a |= 1 << 3;            /* latched in drdy_isr, FW-D08 */
    if (g_loff_bits) a |= 1 << 4;
    a |= (uint16_t)(g_recording ? 1 << 5 : 0);
    return a;
}
static void sample_task(void *arg) {
    /* one daisy read = 2 devices x (24-bit status + 8 x 24-bit) = 54 bytes */
    static uint8_t rx[54]; static uint8_t pay[FRAME_SAMPLES_MAX * SAMPLE_BYTES]; int n = 0; uint32_t first = 0;
    const int per_frame[3] = { 5, 10, 20 };   /* one frame every 20 ms at 250/500/1000 Hz */
    for (;;) {
        ulTaskNotifyTake(pdTRUE, portMAX_DELAY);
        spi_transaction_t t = { .length = 8 * sizeof rx, .rx_buffer = rx }; spi_device_polling_transmit(ads, &t);
        if (n == 0) first = g_sample_index;
        uint8_t *p = pay + n * SAMPLE_BYTES;
        /* device 1 (EEG) is second in the chain: bytes 27..53 ; device 2 first: bytes 0..26 */
        memcpy(p, rx + 27 + 3, 24);           /* ch1-8 EEG */
        memcpy(p + 24, rx + 3, 24);           /* ch9-16 EMG/ENV/spare */
        /* The ADS1299 status word is 1100 + LOFF_STATP[8] + LOFF_STATN[8] + GPIO[4].
           Only STATP was read, which is one bit per site and cannot express three
           colours -- which is why E-27's amber had nowhere to come from.  Both halves
           are captured now: P and N are the positive and negative lead-off detectors of
           the same site, so "one of the two has let go" is a real, measured middle
           state and not an invention. */
        g_loff_p = (uint8_t)(((rx[27] & 0x0F) << 4) | (rx[28] >> 4));
        g_loff_n = (uint8_t)(((rx[28] & 0x0F) << 4) | (rx[29] >> 4));
        g_loff_bits = g_loff_p;                  /* the summary the status frame carries */
        uint16_t aux = aux_bits(); memcpy(p + 48, &aux, 2);
        if (++n >= per_frame[g_rate_code]) { frame_emit(FT_DATA, first, n, pay, n * SAMPLE_BYTES); n = 0; }
    }
}

/* ------------------------------------------------------------------ contact lights (E-27) */
static void lights_write(uint8_t bits) {
    for (int i = 7; i >= 0; i--) { gpio_set_level(PIN_SR_DATA, (bits >> i) & 1); gpio_set_level(PIN_SR_CLK, 1); gpio_set_level(PIN_SR_CLK, 0); }
    gpio_set_level(PIN_SR_LATCH, 1); gpio_set_level(PIN_SR_LATCH, 0);
}
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
void app_main(void) {
    ESP_LOGI(TAG, "EEG field kit firmware — USB only; radio not initialised");
    /* FW-D01 CLOSED.  These were C++ range-based for loops in a .c file, so the project
       did not compile at all.  Plain C, same behaviour. */
    static const int in_pins[]  = { PIN_BTN_A, PIN_BTN_B, PIN_BTN_STOP,
                                    PIN_DRDY, PIN_ENV_CMP };
    static const int out_pins[] = { PIN_CHG_CE, PIN_MIC_MUTE, PIN_LED_PWM,
                                    PIN_SR_DATA, PIN_SR_CLK, PIN_SR_LATCH };
    for (size_t i = 0; i < sizeof in_pins / sizeof in_pins[0]; i++) {
        gpio_set_direction(in_pins[i], GPIO_MODE_INPUT);
        gpio_set_pull_mode(in_pins[i], GPIO_PULLUP_ONLY);
    }
    for (size_t i = 0; i < sizeof out_pins / sizeof out_pins[0]; i++)
        gpio_set_direction(out_pins[i], GPIO_MODE_OUTPUT);
    gpio_set_direction(PIN_VBUS_DET, GPIO_MODE_INPUT);   /* S-01 interlock, FW-D17 */

    /* NVS, I2C, the fuel gauge, the codec and the card.  Everything main.c calls through
       sd_append(), battery_percent(), codec_play_tone_at(), envelope_onset_after() and
       the two identity functions lives in drivers.c and is brought up here. */
    ESP_ERROR_CHECK(drv_init_all());
    gpio_set_level(PIN_MIC_MUTE, 1);                 /* room mic muted unless a scripted window is open */
    /* F-04: the USB iSerialNumber is the PROGRAMME serial TIOV-B-nnnn, written into
       NVS at end-of-line provisioning step 6, NOT the ATECC608B factory serial.  The
       ATECC serial is a second identifier: printed, in the Data Matrix, and checked
       against this one at T5b.  RUL-EEG-021 section B rules this; PKG-EEG-015
       section 5 defines the format. */
    extern void unit_serial_into(char *dst, size_t n);   /* reads NVS key "unit_serial" */
    unit_serial_into(serial_str, sizeof serial_str);
    rb = xRingbufferCreateWithCaps(RING_BYTES, RINGBUF_TYPE_NOSPLIT, MALLOC_CAP_SPIRAM);
    if (rb == NULL) {
        /* Do not carry on: every DATA frame would assert inside xRingbufferSend, and the
           unit would look like a USB fault rather than an out-of-memory one. */
        ESP_LOGE("eeg", "ring buffer of %u bytes would not allocate in PSRAM; "
                        "check CONFIG_SPIRAM_MODE_OCT and the -N16R8 part",
                 (unsigned) RING_BYTES);
        abort();
    }
    const tinyusb_config_t tusb_cfg = { .device_descriptor = &dev_desc, .string_descriptor = str_desc, .string_descriptor_count = 6, .configuration_descriptor = cfg_desc };
    tinyusb_driver_install(&tusb_cfg);
    ads_init();
    xTaskCreatePinnedToCore(sample_task, "sample", 8192, NULL, 23, &sample_task_h, 1);
    gpio_set_intr_type(PIN_DRDY, GPIO_INTR_NEGEDGE); gpio_install_isr_service(0); gpio_isr_handler_add(PIN_DRDY, drdy_isr, NULL);
    xTaskCreate(rx_task, "rx", 4096, NULL, 10, NULL);
    xTaskCreate(status_task, "status", 4096, NULL, 5, NULL);
    xTaskCreate(lights_task, "lights", 2048, NULL, 4, NULL);
}
/* Stubs to be provided by the codec (ES8388 I2S), SD (SDMMC), ATECC608B (I2C) and gauge (MAX17048) drivers:
 *   void sd_append(const uint8_t*, size_t); void codec_play_tone_at(uint32_t); int envelope_onset_after(uint32_t,int);
 *   uint8_t battery_percent(void); uint32_t sd_free_mb(void);
 *   void unit_serial_into(char*, size_t);    -- TIOV-B-nnnn from NVS, F-04
 *   void atecc_serial_into(char*, size_t);   -- factory serial, label/DataMatrix only
 * Signature frames (F-08): every 2048 samples, SHA-256 of the block chained to the previous digest, signed by ATECC608B
 * P-256; emitted as FT_SIGNATURE by the sd/signing task (not shown). */

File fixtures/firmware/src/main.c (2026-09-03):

/*
 * main.c -- entry point for the three EEG-kit fixture controllers.
 *
 * There is nothing in here but the loop, on purpose: everything a reviewer has to check
 * lives either in fixproto.c (the protocol) or in a role file (what the fixture does).
 *
 * Written by hand.  Part of package_v2.3, TI One Voice research programme.
 * Licence: CC BY-SA 4.0.
 */
#include "fixproto.h"
#include "fixhal.h"

#ifndef FIX_MAIN_IS_TEST        /* the host test provides its own main() */
int main(void)
{
    int c;
    hal_init();
    fx_boot();
    for (;;) {
        while ((c = hal_getchar()) >= 0)
            fx_feed(c);
        fx_poll();
    }
}
#endif

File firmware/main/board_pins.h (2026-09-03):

/*
 * board_pins.h -- EEG-CAR-01 Rev B pin map for FW-EEG-001.
 *
 * GENERATED by package_v2.4/tools from design.py.  Do not edit by hand: edit design.py
 * and regenerate, so the firmware and the board can never disagree.
 *
 * ECO-EEG-009: the Rev A map used GPIO35, 36 and 37 for the contact-light shift
 * register.  Those three pins carry the octal PSRAM on the ESP32-S3-DevKitC-1-N16R8
 * and are NOT CONNECTED on this carrier.  GPIO45 is the VDD_SPI strapping pin and is
 * also left open.  microSD is one-bit SDMMC for the same reason.
 *
 * Licence: MIT (firmware).
 */
#ifndef BOARD_PINS_H
#define BOARD_PINS_H

#define BOARD_REV        "B"
#define BOARD_NAME       "EEG-CAR-01"

#define PIN_SR_LATCH     0    /* J7.14  net LED_SR_LATCH */
#define PIN_I2C_SDA      1    /* J7.4   net SDA */
#define PIN_I2C_SCL      2    /* J7.5   net SCL */
#define PIN_ENV_CMP      3    /* J6.13  net ENV_CMP */
#define PIN_BTN_A        4    /* J6.4   net BTN_A */
#define PIN_BTN_B        5    /* J6.5   net BTN_B */
#define PIN_BTN_STOP     6    /* J6.6   net BTN_STOP */
#define PIN_I2S_DIN      7    /* J6.7   net I2S_DIN */
#define PIN_I2S_LRCK     8    /* J6.12  net I2S_LRCK */
#define PIN_I2S_DOUT     9    /* J6.15  net I2S_DOUT */
#define PIN_ADS_CS       10   /* J6.16  net CS */
#define PIN_ADS_MOSI     11   /* J6.17  net MOSI */
#define PIN_ADS_SCLK     12   /* J6.18  net SCLK */
#define PIN_ADS_MISO     13   /* J6.19  net MISO */
#define PIN_ADS_DRDY     14   /* J6.20  net DRDY */
#define PIN_ADS_START    15   /* J6.8   net START */
#define PIN_ADS_RESET    16   /* J6.9   net RESET */
#define PIN_I2S_MCLK     17   /* J6.10  net I2S_MCLK */
#define PIN_I2S_BCLK     18   /* J6.11  net I2S_BCLK */
#define PIN_USB_DN       19   /* J7.20  net USB_DN */
#define PIN_USB_DP       20   /* J7.19  net USB_DP */
#define PIN_MIC_MUTE     21   /* J7.18  net MIC_MUTE */
#define PIN_SD_CMD       38   /* J7.10  net SD_CMD */
#define PIN_SD_CLK       39   /* J7.9   net SD_CLK */
#define PIN_SD_D0        40   /* J7.8   net SD_D0 */
#define PIN_SR_DATA      41   /* J7.7   net LED_SR_DATA */
#define PIN_SR_CLK       42   /* J7.6   net LED_SR_CLK */
#define PIN_UART0_TX     43   /* J7.2   net UART_TX */
#define PIN_UART0_RX     44   /* J7.3   net UART_RX */
#define PIN_VBUS_DET     46   /* J6.14  net VBUS_DET */
#define PIN_CHG_CE       47   /* J7.17  net CHG_CE */
#define PIN_LED_V        48   /* J7.16  net LED_PWM */

/* Header positions that MUST remain unconnected on this hardware */
#define PIN_RESERVED_PSRAM_D5   35
#define PIN_RESERVED_PSRAM_D6   36
#define PIN_RESERVED_PSRAM_D7   37
#define PIN_RESERVED_VDD_SPI    45

/* Front end */
#define N_CH            16
#define N_DEV            2
#define ADS_GAIN_EEG    24
#define ADS_GAIN_EMG    12
#define ADS_GAIN_ENV     1

/* Contact lights: eight two-lead bicolour LEDs between LEDn and the LED_V common.
 * Phase A drives LED_V high and the wanted sites low  -> green.
 * Phase B drives LED_V low  and the wanted sites high -> red.
 * Alternating above 100 Hz shows amber.  At reset LED_V is an input, so nothing can
 * light whatever the shift register contains -- that is the dark-at-boot guarantee. */
#define N_LIGHTS         8
#define LIGHT_PHASE_HZ 240

#endif /* BOARD_PINS_H */

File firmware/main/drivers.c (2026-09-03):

/*
 * drivers.c -- the peripheral drivers main.c calls.
 *
 * FW-D02 to FW-D04, and the link failure they caused.  main.c declared seven functions and
 * nothing defined them, so the project did not link even after it compiled:
 *
 *     sd_append  sd_free_mb  battery_percent  codec_play_tone_at
 *     envelope_onset_after  unit_serial_into  atecc_serial_into
 *
 * Four devices sit behind those seven names: the microSD card on one-bit SDMMC, the
 * MAX17048 fuel gauge on I2C, the ES8388 codec on I2C plus I2S, and the ATECC608B secure
 * element on the same I2C bus.  Pin assignments come from board_pins.h, which is generated
 * from design.py, so they cannot drift from the board.
 *
 * WHAT IS REAL HERE AND WHAT IS NOT.  The bus plumbing, the register sequences, the card
 * mount, the NVS access and the error handling are real and complete.  Two things are
 * deliberately partial and say so at their definition:
 *
 *   codec_play_tone_at()   queues a tone and returns; the sample-accurate scheduling
 *                          against the ADS1299 sample clock (E-13) is not written.
 *   envelope_onset_after() reads the latched comparator bit, which is the hardware half of
 *                          E-12; the sub-sample interpolation is not written.
 *
 * Neither has ever run on hardware.  Nothing in this file has.
 *
 * Licence: MIT.
 */
#include <string.h>
#include <stdio.h>

#include "freertos/FreeRTOS.h"
#include "freertos/task.h"
#include "freertos/queue.h"
#include "driver/i2c.h"
#include "driver/sdmmc_host.h"
#include "esp_vfs_fat.h"
#include "sdmmc_cmd.h"
#include "nvs_flash.h"
#include "nvs.h"
#include "esp_log.h"
#include "esp_check.h"

#include "board_pins.h"
#include "drivers.h"   /* check these definitions against the prototypes main.c uses */

static const char *TAG = "drv";

/* I2C addresses, 7-bit.  ICD-EEG-006 section 2.6 carries the bus map. */
#define ADDR_MAX17048   0x36
#define ADDR_ES8388     0x10
#define ADDR_ATECC608B  0x60

#define I2C_PORT        I2C_NUM_0
#define I2C_HZ          100000
#define SD_MOUNT        "/sdcard"

/* Defined with the NVS helpers below; declared here because unit_serial_into() reads the
   unit serial back long before that section of the file. */
static esp_err_t nvs_open_for(const char *key, nvs_open_mode_t mode, nvs_handle_t *h,
                              const char **part_out);
static bool s_i2c_up;
/* CMD_IDENTIFY advertises what the unit HAS.  It used to derive the codec bit from
 * nothing at all (it was never set) and the ATECC bit from whether the config zone
 * was LOCKED, so a sound board with an unprovisioned ATECC reported neither. */
static bool s_codec_up;
static bool s_atecc_present;
static bool s_sd_up;
static sdmmc_card_t *s_card;
static FILE *s_session;

/* ------------------------------------------------------------------ I2C */
esp_err_t drv_i2c_init(void)
{
    if (s_i2c_up)
        return ESP_OK;
    i2c_config_t c = {
        .mode = I2C_MODE_MASTER,
        .sda_io_num = PIN_I2C_SDA,
        .scl_io_num = PIN_I2C_SCL,
        .sda_pullup_en = GPIO_PULLUP_DISABLE,   /* R94/R95 4k7 are fitted on the carrier */
        .scl_pullup_en = GPIO_PULLUP_DISABLE,
        .master.clk_speed = I2C_HZ,
    };
    ESP_RETURN_ON_ERROR(i2c_param_config(I2C_PORT, &c), TAG, "i2c config");
    ESP_RETURN_ON_ERROR(i2c_driver_install(I2C_PORT, c.mode, 0, 0, 0), TAG, "i2c install");
    s_i2c_up = true;
    return ESP_OK;
}

static esp_err_t i2c_rd(uint8_t addr, uint8_t reg, uint8_t *buf, size_t n)
{
    if (!s_i2c_up)
        return ESP_ERR_INVALID_STATE;
    return i2c_master_write_read_device(I2C_PORT, addr, &reg, 1, buf, n,
                                        pdMS_TO_TICKS(50));
}

static esp_err_t i2c_wr(uint8_t addr, uint8_t reg, uint8_t val)
{
    if (!s_i2c_up)
        return ESP_ERR_INVALID_STATE;
    uint8_t b[2] = { reg, val };
    return i2c_master_write_to_device(I2C_PORT, addr, b, sizeof b, pdMS_TO_TICKS(50));
}

/* ------------------------------------------------------------------ MAX17048 fuel gauge */
uint8_t battery_percent(void)
{
    uint8_t r[2];
    /* SOC register 0x04: 1/256 % per LSB. */
    if (i2c_rd(ADDR_MAX17048, 0x04, r, 2) != ESP_OK)
        return 0xFF;                    /* 0xFF means "not known", not "full" */
    unsigned pct = r[0];                /* high byte is whole percent */
    return pct > 100 ? 100 : (uint8_t) pct;
}

/* ------------------------------------------------------------------ microSD, one-bit SDMMC
 *
 * One-bit, not four: GPIO35/36/37 carry the octal PSRAM on the -N16R8 and are not
 * connected, so D1-D3 do not exist on this carrier (ECO-EEG-009, board_pins.h).
 */
esp_err_t drv_sd_init(void)
{
    if (s_sd_up)
        return ESP_OK;
    sdmmc_host_t host = SDMMC_HOST_DEFAULT();
    host.flags = SDMMC_HOST_FLAG_1BIT;
    host.max_freq_khz = SDMMC_FREQ_DEFAULT;

    sdmmc_slot_config_t slot = SDMMC_SLOT_CONFIG_DEFAULT();
    slot.width = 1;
    slot.clk = PIN_SD_CLK;
    slot.cmd = PIN_SD_CMD;
    slot.d0  = PIN_SD_D0;
    slot.flags = SDMMC_SLOT_FLAG_INTERNAL_PULLUP;

    esp_vfs_fat_sdmmc_mount_config_t mnt = {
        .format_if_mount_failed = false,     /* never silently erase a session card */
        .max_files = 4,
        .allocation_unit_size = 32 * 1024,
    };
    esp_err_t e = esp_vfs_fat_sdmmc_mount(SD_MOUNT, &host, &slot, &mnt, &s_card);
    if (e != ESP_OK) {
        ESP_LOGE(TAG, "microSD mount failed: %s", esp_err_to_name(e));
        return e;
    }
    s_sd_up = true;
    return ESP_OK;
}

esp_err_t drv_sd_open_session(const char *name)
{
    if (!s_sd_up)
        return ESP_ERR_INVALID_STATE;
    char path[64];
    snprintf(path, sizeof path, SD_MOUNT "/%s.eeg", name);
    s_session = fopen(path, "ab");
    return s_session ? ESP_OK : ESP_FAIL;
}

/* The authoritative copy of the session (E-20).  Appends are buffered by the VFS; the
 * caller flushes at block boundaries. */
void sd_append(const uint8_t *p, size_t n)
{
    if (s_session && p && n)
        fwrite(p, 1, n, s_session);
}

void drv_sd_flush(void)
{
    if (s_session)
        fflush(s_session);
}

uint32_t sd_free_mb(void)
{
    if (!s_sd_up || !s_card)
        return 0;
    FATFS *fs;
    DWORD free_clusters;
    if (f_getfree("0:", &free_clusters, &fs) != FR_OK)
        return 0;
    uint64_t free_bytes = (uint64_t) free_clusters * fs->csize * FF_MAX_SS;
    return (uint32_t) (free_bytes / (1024 * 1024));
}

/* ------------------------------------------------------------------ ES8388 codec
 *
 * Minimum viable init: power up, I2S slave, 16-bit, headphone out enabled at a level the
 * firmware clamps.  E-29 caps the acoustic output at 100 dB SPL and that clamp is applied
 * here, in the one place the level is set, rather than trusted to the host.
 */
#define ES8388_HP_MAX 0x1E        /* -3 dB of full scale; see FW-EEG-001 section 5.9 */
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

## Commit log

2026-09-08 WP1 -- revision bookkeeping and the Rev B withdrawal ECO
    ECO-EEG-030: an external layout engineer read the Rev B board between 3 and 5
    September 2026, declined the paid review and advised a redesign from the
    schematic. Rev B is withdrawn from fabrication; no board is ordered from it and
    its data stays in the tree as history. Rev C is opened as a board revision that
    changes footprints, part numbers and the layout only -- no pin assignment, net
    name, connector coordinate, outline, stack-up, zone split, keep-out or star
    point moves. RFQ-EEG-002A is re-scoped from "review this routing" to "review
    the layout contractor's placement of Rev C".
    Also rules the document and ECO number namespaces i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
    [design.py]
2026-09-08 WP2 -- BOM and footprint corrections (ECO-EEG-031)
    Four part numbers could not be bought as written or could not be fitted:
    U1-U3 TI OPA4376AIDR on a SOIC-14 land. The quad OPA4376 is made only in
    TSSOP-14 (PW); OPA4376AIDR is not an orderable part number. Now
    OPA4376AIPWR on TSSOP-14_4.4x5mm_P0.65mm. Pin numbering is identical
    between the packages, so no net moved -- measured against the released
    IPC-D-356A netlist, identical across all 156 nets.
    L1 Murata BLM18PG601SN1D. The impedance code does mean 600 ohm at
    100 MHz; the PG large-current series is simply not made at 600 ohm in
    1608, whose range stops at 470 ohm.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
    [EEG-CAR-01_RevC_BOM.csv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]
2026-09-08 WP3 -- the seven findings encoded as rules, and Rev B regraded under them
    The Rev B DRC report says "VIOLATIONS: 0 -- none. The board passes every rule
    listed above" and it is correct. The rule set had twelve rules and none of them
    looked for a via in a pad, a dangling end, a redundant loop, an acute corner, an
    off-centre pad entry, or a conductor narrower than its net class needs -- the
    last of which could not be looked for, because there were no net classes with
    minima. ECO-EEG-032 closes that.
    One source of truth: tools/rules.py. Checked on real geometry by the in-house
    DRC, exported to KiCad as kicad/EEG-CAR-01_RevC.kicad_dru (37 rules, brackets
    validated on every emit). Eight net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
    [build_board.py, design.py, drc.py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]
2026-09-08 WP4 -- the native KiCad schematic (ECO-EEG-033, part 1)
    Finding 7 of ECO-EEG-030: no native schematic exists. The eight-sheet PDF is
    eight matplotlib drawings and carries no netlist, so no reviewer can import it,
    check it or route from it. This is the answer.
    Ten KiCad 8 files: a root block diagram and nine sheets, one per block, from the
    same design.py data the PDF is drawn from. All 211 designators placed, and the
    assignment is checked to be a partition of design.C. Power and ground global
    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
    [EEG-CAR-01_RevC.kicad_sch, EEG-CAR-01_RevC_10_power.kicad_sch, EEG-CAR-01_RevC_20_isolation_usb.kicad_sch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]
2026-09-08 WP5 -- unrouted Rev C board, project file and DXF (ECO-EEG-033, part 2)
    kicad/EEG-CAR-01_RevC.kicad_pcb at (kicad_pcb (version 20240108)). The Rev B
    writer stays on the KiCad 5 dialect and is untouched: that was right for a
    fabrication set going to houses on older tools, and is wrong here, because net
    classes, rule areas and custom rules do not survive it and they are the point.
    outline on Edge.Cuts, four-layer stack-up in (setup)
    211 footprints with pads and nets; NO track, NO via, NO arc
    AGND_REF and DGND zones on In1.Cu and In2.Cu, split at x = 62 mm
    rule areas under exactly the names the .kicad_dru refers to:
    ISOLATION_KEEPOUT (all four copper layers), ANALOGUE_ZONE, DIGITA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
    [EEG-CAR-01_RevC.kicad_pcb, EEG-CAR-01_RevC_outline_and_fixed_connectors.dxf]
2026-09-08 WP6 -- 3D bodies and the collision check (ECO-EEG-033, part 3)
    Finding 6 of ECO-EEG-030: no module outlines exist, so no placement could be
    shown free of interference. Now it can, and it is not.
    cadquery could NOT be installed here -- 472 MB free where cadquery-ocp needs
    several times that -- so mech_gen.py cannot be imported on this machine and no
    printed part was regenerated. tools/step_write.py writes the bodies the check
    needs from first principles with no dependency: FACETED_BREP, planar faces, one
    solid per extruded polygon. No STEP reader was available to verify the files;
    they are checked structurally and that is all that is claimed.
    WHAT THE CHECK FOUND. Three of the four case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
    [C_0603_1608Metric.step, DIN42802_1p5mm_Socket.step, EEG-CAR-01_RevC.kicad_pcb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]
2026-09-08 WP7 -- LAY-EEG-034, the carrier layout rule sheet (ECO-EEG-033, part 4)
    A controlled document that is also generated: the net-class table and the
    geometry table are transcribed from tools/rules.py by tools/emit_rule_sheet.py,
    so the sheet the contractor signs against and the .kicad_dru their DRC loads
    come from one source and cannot drift. The prose is written.
    Eight sections: scope and precedence (design.py governs, and this sheet is part
    of the order specification -- a departure is a layout error); board and
    stack-up, citing DSN-EEG-003 section 3.2 in four lines; zoning and star points;
    the isolation keep-out; the eight net classes with a derivation for each and a
    `confirm` column markin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
    [emit_revc.py, emit_rule_sheet.py]
2026-09-08 WP8 -- the handover set and its README (ECO-EEG-033, part 5)
    kicad/RevC_layout_inputs/: 51 files, 2.6 MB. The project, the ten schematic
    sheets, the symbol library, the board, the .kicad_dru, the netlist, the BOM and
    the footprint audit, the two provisional CPLs, the DXF, 25 STEP bodies, the
    collision report, the rule sheet in both forms, a SHA-256 for every file, and
    README_layout_inputs.md.
    The README says the four things a contractor otherwise has to guess:
    open the .kicad_pro and NOT the board -- a board opened alone has none of the
    net classes, none of the 156 assignments and no track_dangling severity;
    the KiCad version, with an offer to re-emit for a different one, and the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
    [C_0603_1608Metric.step, DIN42802_1p5mm_Socket.step, EEG-CAR-01_RevC.kicad_pcb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]
2026-09-08 WP9 (cont) -- the release-state statements in the four re-issued documents
    Bumping a document's letter while leaving a false statement inside it is worse
    than leaving it at the old letter. The four documents this round re-issued had
    eleven live claims that the fabrication data is "released for review under
    RFQ-EEG-002A and not for fabrication". It is not: Rev B is withdrawn and Rev C
    is unrouted.
    DSN-EEG-003 Rev D 5 statements: the front matter, the "can you fabricate
    the bare board" row, adversarial-review finding 1 (now
    CLOSED, and not the way it expected to close), the
    section 8 release paragraph, and the RFQ cover t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
2026-09-08 Report -- docs/RevC_work_report_2026-09.md
    What was run and what it printed, including everything that was NOT run and why;
    the ten places the repository contradicted the brief; nine assumptions, each
    registered or flagged; eight open questions, each with a recommended default;
    the handover file list; and the commits.
    Also corrects the release-state note the simulator itself writes into
    SIM-EEG-018, which still said the fabrication data was RELEASED FOR REVIEW. It
    is generated, so the fix is in tools/simulate_production.py.
    The four headline findings, none of which was in the brief:
    the tactile switch is a 12 x 12 mm part on a 6 x 6 mm land (ECO-EEG-031);
    four ICD connector coordinat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
    [simulate_production.py]
2026-09-10 ECO-EEG-035 -- the gaps eleven quotations exposed
    Six work packages from the September 2026 brief. Two were decisions and
    produced no change to any document, which is the outcome, not an omission.
    No requirement, limit, netclass width, governing figure or part number was
    changed. design.py, rules.py, DSN-EEG-003, QP-EEG-010 and RFQ-EEG-001 are
    untouched, and the ATECC608B configuration is NOT marked approved.
    WP1 -- datasheets and the licence position
    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
    [EEG_kit_BOM_INTERNAL_RevC_costed.xlsx, EEG_kit_BOM_for_bidders_RevC.xlsx]
2026-09-10 ECO-EEG-036 -- closing ECO-EEG-035 so it can be published
    Two of ECO-EEG-035's findings contradicted statements already made to
    manufacturers. This resolves them. No requirement or limit was changed;
    QP-EEG-010 and design.py's part number for J15-J17 are untouched.
    WP-A -- what are J15, J16 and J17? (INVESTIGATION, no part chosen)
    reports/INVESTIGATION_din42802_sockets_J15_J17.md.
    Provenance: SLB1,5-F / LB-I1,5 entered at b18782a, the ROOT COMMIT,
    byte-identical to today, and was never verified. The package never
    claimed it was: AVL-EEG-017 1.4.1 has always said "a class of part, not
    a confirmed PCB part", "no catalogue part has been confirmed to fit it",
    no qualified vendor, 1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
    [design.py]
2026-09-10 WP-E -- dist/vendor_links.md, commit-pinned
    Every link pinned to 3426914 rather than main, so a URL quoted in an email
    cannot drift when the repository moves. Each row carries the SHA-256 of the
    file as it stands at that commit; three were spot-checked against
    raw.githubusercontent.com and match.
    Organised by scope rather than by company: the contact register holds 45
    manufacturers and the repository does not record which eleven are currently
    mid-quotation, so guessing would have put an unverified list into the one
    page the emails will quote. PCBCart and Wuhan Greentek are named because
    the repository evidences their involvement.
    Carries the two things a manufacturer must read before prici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

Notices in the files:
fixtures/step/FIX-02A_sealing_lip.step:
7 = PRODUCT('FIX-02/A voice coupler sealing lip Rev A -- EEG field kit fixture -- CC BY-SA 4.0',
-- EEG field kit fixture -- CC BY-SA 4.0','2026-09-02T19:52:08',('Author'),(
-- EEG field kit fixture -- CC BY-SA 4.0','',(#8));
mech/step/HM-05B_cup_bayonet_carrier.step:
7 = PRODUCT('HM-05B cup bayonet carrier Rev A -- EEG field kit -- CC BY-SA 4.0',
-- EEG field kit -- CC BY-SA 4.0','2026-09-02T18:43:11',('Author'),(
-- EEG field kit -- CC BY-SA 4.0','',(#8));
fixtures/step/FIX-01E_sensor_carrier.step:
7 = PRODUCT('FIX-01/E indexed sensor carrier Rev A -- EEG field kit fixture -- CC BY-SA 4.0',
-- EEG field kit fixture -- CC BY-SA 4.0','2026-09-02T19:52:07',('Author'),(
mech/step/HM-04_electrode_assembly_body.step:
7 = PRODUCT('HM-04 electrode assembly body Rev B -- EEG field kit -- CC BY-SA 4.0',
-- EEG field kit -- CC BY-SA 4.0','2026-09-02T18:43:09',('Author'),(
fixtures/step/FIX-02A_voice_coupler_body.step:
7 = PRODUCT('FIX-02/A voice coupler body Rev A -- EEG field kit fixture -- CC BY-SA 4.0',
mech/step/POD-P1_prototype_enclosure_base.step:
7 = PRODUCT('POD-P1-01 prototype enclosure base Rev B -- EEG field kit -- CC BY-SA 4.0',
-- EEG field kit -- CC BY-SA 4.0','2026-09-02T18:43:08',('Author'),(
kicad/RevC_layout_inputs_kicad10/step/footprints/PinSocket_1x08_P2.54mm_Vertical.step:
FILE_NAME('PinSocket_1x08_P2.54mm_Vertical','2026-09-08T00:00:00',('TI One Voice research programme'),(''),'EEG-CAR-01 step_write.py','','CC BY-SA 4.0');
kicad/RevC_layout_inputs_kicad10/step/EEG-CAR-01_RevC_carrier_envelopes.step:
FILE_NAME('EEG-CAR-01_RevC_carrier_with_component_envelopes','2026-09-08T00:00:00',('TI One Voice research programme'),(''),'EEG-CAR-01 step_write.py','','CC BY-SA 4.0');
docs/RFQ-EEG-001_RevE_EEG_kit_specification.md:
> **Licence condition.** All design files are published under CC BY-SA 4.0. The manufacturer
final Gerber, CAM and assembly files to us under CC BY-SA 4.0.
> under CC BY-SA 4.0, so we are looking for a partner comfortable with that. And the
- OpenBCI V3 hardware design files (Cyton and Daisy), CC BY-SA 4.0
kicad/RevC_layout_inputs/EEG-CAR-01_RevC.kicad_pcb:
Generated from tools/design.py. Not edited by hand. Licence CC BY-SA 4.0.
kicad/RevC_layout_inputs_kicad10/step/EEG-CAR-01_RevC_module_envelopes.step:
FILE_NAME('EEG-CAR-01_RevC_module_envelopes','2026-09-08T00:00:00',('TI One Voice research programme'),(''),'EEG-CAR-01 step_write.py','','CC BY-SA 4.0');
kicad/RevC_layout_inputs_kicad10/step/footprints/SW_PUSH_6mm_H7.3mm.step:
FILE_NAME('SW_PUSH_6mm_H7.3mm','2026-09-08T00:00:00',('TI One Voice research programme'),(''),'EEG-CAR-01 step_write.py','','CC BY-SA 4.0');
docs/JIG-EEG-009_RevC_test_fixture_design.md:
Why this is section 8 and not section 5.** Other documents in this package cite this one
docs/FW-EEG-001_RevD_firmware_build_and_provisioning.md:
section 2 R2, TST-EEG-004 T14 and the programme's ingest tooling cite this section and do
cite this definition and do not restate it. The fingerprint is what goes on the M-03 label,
